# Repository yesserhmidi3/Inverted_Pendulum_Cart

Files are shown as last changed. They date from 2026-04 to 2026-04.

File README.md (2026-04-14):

# Inverted Pendulum on a Cart — Embedded Control System

> A full-stack mechatronics project: mechanical design, mathematical modeling, and real-time PID control on an ESP32 — balancing an inverted pendulum through cart motion.

<p align="center">
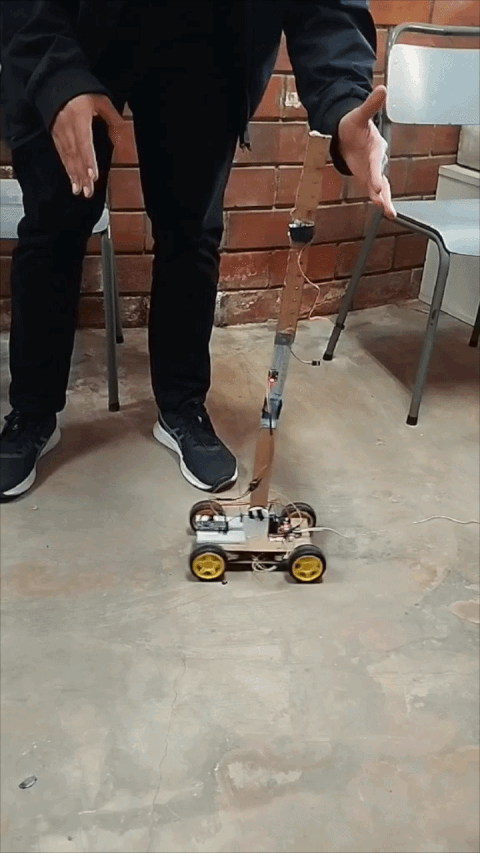
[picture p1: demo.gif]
Inverted Pendulum Demo
  
</p>

---

## Overview

This project implements a **real-time control system** for an **Inverted Pendulum on a Cart** — a classic benchmark in control theory. The goal is to:

1. **Model the Dynamics** using Lagrangian mechanics to understand the non-linear relationship between wheel torque and pendulum angle.
2. **Stabilize** the pendulum at the unstable upright equilibrium point by applying precise horizontal acceleration via a 4WD DC motor chassis.

The system was developed from the ground up: mechanical structure (SolidWorks), mathematical derivation (Lagrangian), and embedded firmware (ESP32 + C++).

---

## Control Strategy

### Modeling
The system dynamics were derived using **Lagrangian Mechanics** ($L = T - V$). The state vector is defined as $X = [x, \dot{x}, \theta, \dot{\theta}]^T$, representing cart position, cart velocity, pendulum angle, and angular velocity. 

### Stabilization
The controller is designed around the **linearized model** at the upright position ($\theta = 0$). 
* **PID Control:** A high-frequency control loop runs on the ESP32, processing IMU (MPU6050) feedback to calculate the required motor PWM for the 4WD system.
* **Mass Tuning:** To increase system inertia and lower the center of mass for better stability, the pendulum mass was modified by mounting two **MG995 servos** as dead weights in the middle of the rod.

---

## System Architecture

```text
┌────────────────┐      PWM / Direction      ┌────────────────┐
│     ESP32      │ ────────────────────────> │  L298N Driver  │
│  (PID Control) │                           │ (Motor Control)│
└───────┬────────┘                           └───────┬────────┘
        │                                            │
        │           ┌────────────────┐               │ Drive
    Feedback        │  MPU6050 IMU   │               │ Signal
   (Angle/Acc)      │ (On Pendulum)  │               │
        │           └───────┬────────┘               ▼
        │                   │                ┌────────────────┐
        └───────────────────┴─────────────── │ 4WD DC Chassis │
                                             │ (Yellow Motors)│
                                             └────────────────┘
```
                                             
---

## System Parameters

| Parameter | Value |
| :--- | :--- |
| **Total Cart Mass (M)** | ~0.5 kg |
| **Pendulum Mass (m)** | ~150g (Modified with 2x MG995 Servos) |
| **Pendulum Length (L)** | 0.65 m |
| **MCU** | ESP32 (Dual-Core) |
| **Actuators** | 4x Geared Yellow DC Motors |
| **Sensor** | MPU6050 (Accelerometer/Gyroscope) |

---

## Software Stack

| Layer | Tool / Framework |
|---|---|
| Mechanical CAD | SolidWorks |
| Mathematical Modeling | Lagrangian Mechanics |
| Embedded Firmware | Arduino / C++ (ESP32) |
| Communication | Serial Monitor / Teleplot |

---

## Repository Structure
* **`/cad`**: SolidWorks assembly and part files for the 4WD chassis and pendulum holder.
* **`/code`**: ESP32 source code, PID implementation, and MPU6050 calibration logic.

---

## Setup & Usage

1. **Hardware:**
   * Assemble the 4WD chassis using the provided SolidWorks designs.
   * Mount the MPU6050 IMU on the pendulum (adjust code if orientation changes).
   * Ensure the two MG995 servos are secured to the middle of the pendulum rod to achieve the specified inertia.
2. **Software:**
   * Open the `.ino` file in the `/code` folder.
   * Calibrate the IMU offsets for the gyro and accelerometer.
   * Upload the code to the ESP32 via Arduino IDE.

---

## Results

- Achieved stable upright balance using 4-wheel drive movement.
- Successfully accounted for the increased inertia provided by the additional servo weights.
- Handled real-world disturbances and recovery maneuvers.

---
*This project was completed for academic purposes focusing on Non linear systems, Control Theory, and Robotics.*

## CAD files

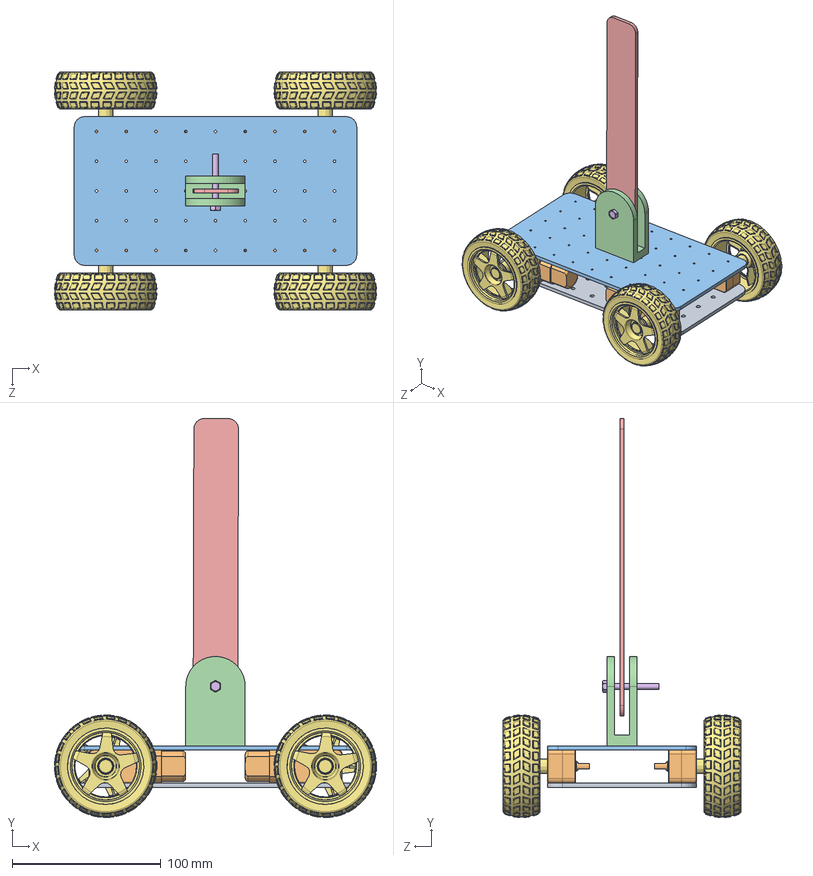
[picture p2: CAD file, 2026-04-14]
cad/Assem.SLDASM
216.5 x 268.2 x 160.0 mm
bottom_part
Motor x 4
top_part
Rot
pendulum
hex screw_am
Wheel D65x25 x 4

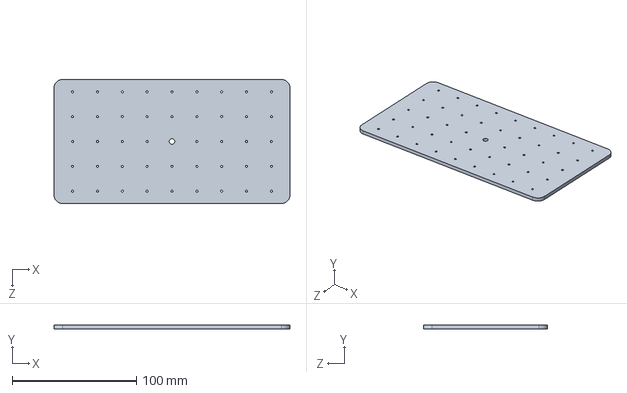
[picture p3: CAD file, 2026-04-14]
cad/top_part.SLDPRT
190.0 x 3.00 x 100.0 mm

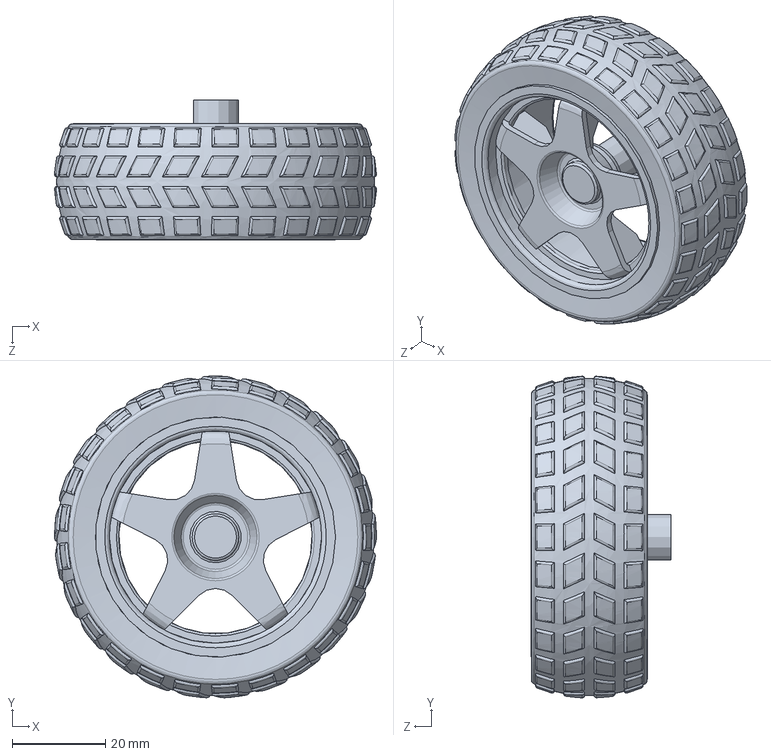
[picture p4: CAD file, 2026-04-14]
cad/Wheel D65x25.SLDPRT
68.9 x 68.8 x 30.0 mm

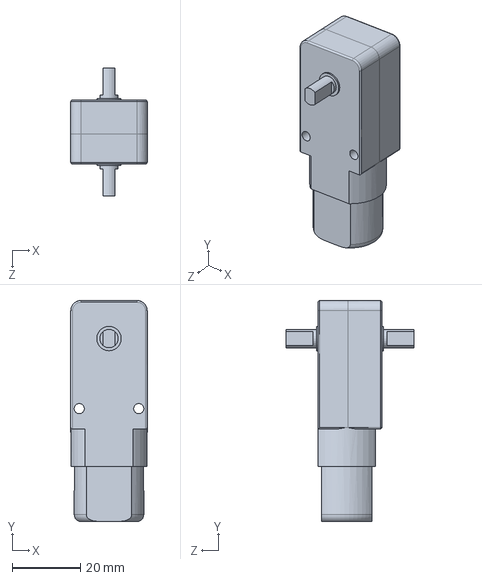
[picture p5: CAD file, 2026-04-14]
cad/Motor.SLDPRT
22.5 x 65.0 x 37.6 mm

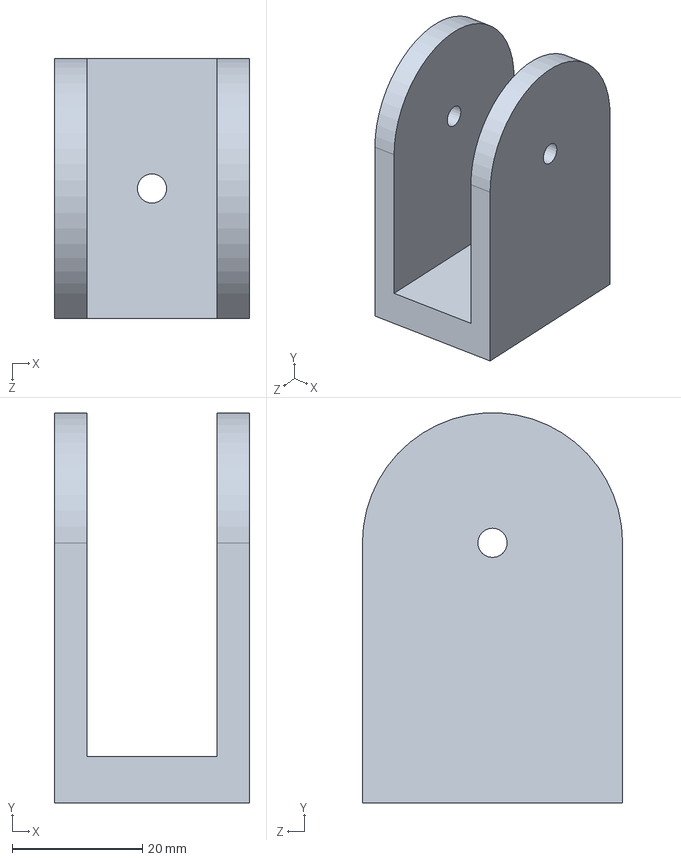
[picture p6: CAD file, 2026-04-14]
cad/Rot.SLDPRT
30.0 x 60.0 x 40.0 mm

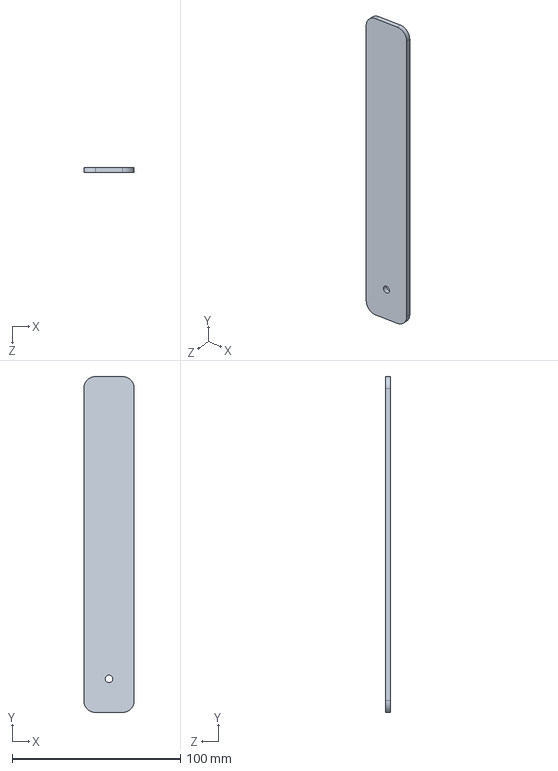
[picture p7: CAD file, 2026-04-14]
cad/pendulum.SLDPRT
30.0 x 200.0 x 3.00 mm

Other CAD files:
cad/bottom_part.SLDPRT

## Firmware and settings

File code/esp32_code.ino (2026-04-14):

#include "motor.h"
#include "mpu.h"
#include "pid.h"

static PidBlock sBalancePid;
static const float TARGET_ANGLE_DEG = 0.0f;
static const float MOTOR_POLARITY = -1.0f;
static const float FALL_ANGLE_LIMIT_DEG = 45.0f;
static const float UPRIGHT_DEADBAND_DEG = 0.5f;
static uint32_t sLastControlMicros = 0;
static uint32_t sLastPrintMs = 0;

static void printTelemetry(float thetaDeg, float pidCmd, float reqCmd, const char *state) {
  uint32_t nowMs = millis();
  if (nowMs - sLastPrintMs < 100) {
    return;
  }

  sLastPrintMs = nowMs;
  Serial.print("state=");
  Serial.print(state);
  Serial.print(" theta=");
  Serial.print(thetaDeg, 2);
  Serial.print(" pid=");
  Serial.print(pidCmd, 3);
  Serial.print(" req=");
  Serial.print(reqCmd, 3);
  Serial.print(" applied=");
  Serial.println(motorGetLastAppliedCommand(), 3);
}

void setup() {
  Serial.begin(115200);

  bool motorOk = motorBegin();
  bool imuOk = pendulumAngleBegin();

  pidInit(sBalancePid, 0.7f, 0.05f, 0.0f, -1.0f, 1.0f);
  pidSetIntegratorLimits(sBalancePid, -0.4f, 0.4f);
  sLastControlMicros = micros();

  if (!imuOk) {
    Serial.println("MPU init failed");
  }
  if (!motorOk) {
    Serial.println("Motor init failed");
  }
}

void loop() {
  float thetaDeg = 0.0f;
  if (!pendulumAngleWork(thetaDeg)) {
    motorStop();
    printTelemetry(thetaDeg, 0.0f, 0.0f, "IMU_FAIL");
    delay(5);
    return;
  }

  if (thetaDeg > FALL_ANGLE_LIMIT_DEG || thetaDeg < -FALL_ANGLE_LIMIT_DEG) {
    motorStop();
    pidReset(sBalancePid);
    sLastControlMicros = micros();
    printTelemetry(thetaDeg, 0.0f, 0.0f, "CUT_OFF");
    delay(5);
    return;
  }

  if (thetaDeg >= -UPRIGHT_DEADBAND_DEG && thetaDeg <= UPRIGHT_DEADBAND_DEG) {
    motorStop();
    pidReset(sBalancePid);
    sLastControlMicros = micros();
    printTelemetry(thetaDeg, 0.0f, 0.0f, "ZERO_HOLD");
    delay(5);
    return;
  }

  uint32_t now = micros();
  float dt = (now - sLastControlMicros) * 1e-6f;
  sLastControlMicros = now;
  if (dt <= 0.0f || dt > 0.1f) {
    dt = 0.01f;
  }

  float motorCmd = pidUpdate(sBalancePid, TARGET_ANGLE_DEG, thetaDeg, dt);
  float motorDriveCmd = MOTOR_POLARITY * motorCmd;
  motorSetNormalized(motorDriveCmd);

  printTelemetry(thetaDeg, motorCmd, motorDriveCmd, "RUN");

  delay(5);
}

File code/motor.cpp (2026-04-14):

#include "motor.h"

#include <math.h>

static const int MOTOR_L_HIGH_PIN = 14;
static const int MOTOR_L_LOW_PIN = 12;
static const int MOTOR_R_HIGH_PIN = 27;
static const int MOTOR_R_LOW_PIN = 26;

static const int PWM_FREQ = 5000;
static const int PWM_RESOLUTION = 8;
static const int PWM_MAX_DUTY = (1 << PWM_RESOLUTION) - 1;
static const float MIN_EFFECTIVE_COMMAND = 0.45f;
static const float MAX_EFFECTIVE_COMMAND = 1.0f;
static const float STOP_EPSILON = 0.001f;
static float sLastAppliedCommand = 0.0f;

static float clampf(float value, float minValue, float maxValue) {
	if (value < minValue) {
		return minValue;
	}
	if (value > maxValue) {
		return maxValue;
	}
	return value;
}

bool motorBegin() {
	pinMode(MOTOR_L_HIGH_PIN, OUTPUT);
	pinMode(MOTOR_L_LOW_PIN, OUTPUT);
	pinMode(MOTOR_R_HIGH_PIN, OUTPUT);
	pinMode(MOTOR_R_LOW_PIN, OUTPUT);
	digitalWrite(MOTOR_L_HIGH_PIN, LOW);
	digitalWrite(MOTOR_L_LOW_PIN, LOW);
	digitalWrite(MOTOR_R_HIGH_PIN, LOW);
	digitalWrite(MOTOR_R_LOW_PIN, LOW);

	bool lHighOk = ledcAttach(MOTOR_L_HIGH_PIN, PWM_FREQ, PWM_RESOLUTION);
	bool lLowOk = ledcAttach(MOTOR_L_LOW_PIN, PWM_FREQ, PWM_RESOLUTION);
	bool rHighOk = ledcAttach(MOTOR_R_HIGH_PIN, PWM_FREQ, PWM_RESOLUTION);
	bool rLowOk = ledcAttach(MOTOR_R_LOW_PIN, PWM_FREQ, PWM_RESOLUTION);
	ledcWrite(MOTOR_L_HIGH_PIN, 0);
	ledcWrite(MOTOR_L_LOW_PIN, 0);
	ledcWrite(MOTOR_R_HIGH_PIN, 0);
	ledcWrite(MOTOR_R_LOW_PIN, 0);

	motorStop();
	return lHighOk && lLowOk && rHighOk && rLowOk;
}

void motorSetNormalized(float command) {
	float saturated = clampf(command, -1.0f, 1.0f);
	float magnitude = fabsf(saturated);

	if (magnitude <= STOP_EPSILON) {
		motorStop();
		return;
	}

	magnitude = clampf(magnitude, MIN_EFFECTIVE_COMMAND, MAX_EFFECTIVE_COMMAND);
	float sign = saturated >= 0.0f ? 1.0f : -1.0f;
	sLastAppliedCommand = sign * magnitude;
	int duty = (int)(magnitude * (float)PWM_MAX_DUTY + 0.5f);
	if (duty > PWM_MAX_DUTY) {
		duty = PWM_MAX_DUTY;
	}

	if (saturated >= 0.0f) {
		ledcWrite(MOTOR_L_HIGH_PIN, duty);
		ledcWrite(MOTOR_L_LOW_PIN, 0);
		ledcWrite(MOTOR_R_HIGH_PIN, duty);
		ledcWrite(MOTOR_R_LOW_PIN, 0);
	} else {
		ledcWrite(MOTOR_L_HIGH_PIN, 0);
		ledcWrite(MOTOR_L_LOW_PIN, duty);
		ledcWrite(MOTOR_R_HIGH_PIN, 0);
		ledcWrite(MOTOR_R_LOW_PIN, duty);
	}
}

void motorStop() {
	sLastAppliedCommand = 0.0f;
	ledcWrite(MOTOR_L_HIGH_PIN, 0);
	ledcWrite(MOTOR_L_LOW_PIN, 0);
	ledcWrite(MOTOR_R_HIGH_PIN, 0);
	ledcWrite(MOTOR_R_LOW_PIN, 0);
}

float motorGetLastAppliedCommand() {
	return sLastAppliedCommand;
}
